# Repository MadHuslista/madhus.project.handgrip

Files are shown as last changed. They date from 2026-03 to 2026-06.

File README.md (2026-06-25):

# Handgrip Suite

- [Handgrip Suite](#handgrip-suite)
  - [Summary](#summary)
    - [System Architecture](#system-architecture)
    - [Components](#components)
  - [Quickstart](#quickstart)
    - [Firmware Workspace](#firmware-workspace)
    - [Python Workspace](#python-workspace)
    - [What to read and when](#what-to-read-and-when)
  - [Validation](#validation)
  - [Documentation map](#documentation-map)

## Summary

- **Handgrip Suite** is an end-to-end suite for acquiring, visualizing, calibrating, and analyzing handgrip force data.
- The system combines a **target handgrip device** based on Arduino Nano + HX711 load-cell acquisition with a **reference force chain** based on a PM58 load cell connected to a high-speed RS485 acquisition board.
- The host software stack is split into 5 focused components: `RS485_GUI`, `LSL_Bridge`, `LSL_Viewer`, `Handgrip_Calibration`, and `Handgrip_Analysis`.
- The documentation is organized for progressive discovery: each README provides a self-contained overview of its component, with links to more detailed workflows and references.
- This root README is intentionally short. The full documentation map starts at [docs/index.md](docs/index.md).

### System Architecture

```mermaid
flowchart TD
    Streams>"Dual Streams"]
    Hardware("PM58 Load Cell \n& Acquisition Board\n(reference)") -->|Modbus RS485| RS485_GUI(RS485 GUI)
    RS485_GUI -->|ZeroMQ IPC| Bridge(LSL_Bridge)
    FW("Handgrip_Firmware \nADC: HX711 &\nMCU: Arduino Nano\n(target)\n") -->|UART Serial| Bridge
    Bridge --> |s: HandgripReference| Streams
    Bridge ~~~ |"LSL Streams\n Sync capables"| Streams
    Bridge --> |s: HandgripTarget| Streams
    Streams -->| Live | Viewer(LSL_Viewer)
    Streams -->|Captured Data| Calibration(Handgrip_Calibration)
    Calibration -->|Calibration Data/Files| Analysis(Handgrip_Analysis)
```

### Components

Following the system architecture, here are the entry points and purposes for each module:

- [PM58 Load Cell & Acquisition Board](docs/workflows/physical-setup.md): Reference-force sensing hardware and wiring stack. 
- [RS485_GUI](RS485_GUI/docs/index.md): Control interface for reading PM58 data and streaming it to LSL_Bridge in real time. 
- [Handgrip_Firmware](Handgrip_Firmware/docs/index.md): Firmware that samples HX711 load-cell data and sends UART telemetry. 
- [LSL_Bridge](LSL_Bridge/docs/index.md): Middleware that ingests target/reference signals and publishes synchronized LSL streams.
- [LSL_Viewer](LSL_Viewer/docs/index.md): Real-time dashboard for monitoring synchronized LSL streams.
- [Handgrip_Calibration](Handgrip_Calibration/docs/index.md): Identifies the best mathematical model to map raw ADC counts to Newtons using reference-force ground truth. 
- [Handgrip_Analysis](Handgrip_Analysis/docs/index.md): DSP analysis workflow for selecting production filter parameters for LSL_Bridge.

## Quickstart

### Firmware Workspace

Install PlatformIO from: 

| Option | Link |
| --- | --- |
| CLI Standalone | [https://docs.platformio.org/en/latest/core/installation/index.html](https://docs.platformio.org/en/latest/core/installation/index.html) |
| VSCode extension [**Recommended**] | [https://marketplace.visualstudio.com/items?itemName=platformio.platformio-ide](https://marketplace.visualstudio.com/items?itemName=platformio.platformio-ide) |

Ensure PlatformIO binaries are in your PATH: 
- [https://docs.platformio.org/en/stable/core/installation/shell-commands.html](https://docs.platformio.org/en/stable/core/installation/shell-commands.html)

Firmware is built with PlatformIO from the root `platformio.ini`
Run from the repository root:

```bash
pio run -e nanoatmega328
pio run -e nanoatmega328 -t upload
```

Validate connection and data reception with:

```bash
pio device monitor -e nanoatmega328
```
Expect to see a stream of telemetry lines with raw ADC counts and timestamps. 

Read [Handgrip_Firmware/docs/workflow.md](Handgrip_Firmware/docs/workflow.md) for the full workflow, or before uploading or changing firmware constants.

### Python Workspace

Install UV Python package manager from: 
- [https://docs.astral.sh/uv/getting-started/installation/](https://docs.astral.sh/uv/getting-started/installation/)

Run from the repository root:

```bash
uv venv .venv
source .venv/bin/activate
uv sync
```

From repository root, run the live system in this order:

```bash
# Terminal 1 — reference acquisition board GUI / IPC publisher
uv run rs485-gui serial.default_port=/dev/ttyUSB_RS485

# Terminal 2 — target/reference bridge to Lab Streaming Layer
uv run lsl-bridge serial.port=/dev/ttyUSB_TARGET

# Terminal 3 — live viewer
uv run lsl-viewer
```

This brings up the reference GUI/IPC publisher, the `HandgripTarget` and `HandgripReference` LSL streams, and the viewer UI. For the full operational path, read [docs/workflows/full-live-viewer-quickstart.md](docs/workflows/full-live-viewer-quickstart.md).

### What to read and when

| I want to… | Start here | Then |
| --- | --- | --- |
| Understand the whole suite | [docs/system-overview.md](docs/system-overview.md) | [docs/workflows/handgrip-calibration.md](docs/workflows/handgrip-calibration.md), [docs/workflows/handgrip-analysis.md](docs/workflows/handgrip-analysis.md) |
| Connect hardware | [docs/workflows/physical-setup.md](docs/workflows/physical-setup.md) | [Handgrip_Firmware/docs/workflow.md](Handgrip_Firmware/docs/workflow.md) |
| Start the full live system | [docs/workflows/full-live-viewer-quickstart.md](docs/workflows/full-live-viewer-quickstart.md) | — |
| Validate target path only | [docs/workflows/target-only-quickstart.md](docs/workflows/target-only-quickstart.md) | — |
| Validate reference path only | [docs/workflows/reference-only-quickstart.md](docs/workflows/reference-only-quickstart.md) | — |
| Build/upload firmware | [Handgrip_Firmware/docs/workflow.md](Handgrip_Firmware/docs/workflow.md) | [Handgrip_Firmware/docs/index.md](Handgrip_Firmware/docs/index.md) |
| Calibrate the handgrip | [docs/workflows/handgrip-calibration.md](docs/workflows/handgrip-calibration.md) | [Handgrip_Calibration/docs/workflow.md](Handgrip_Calibration/docs/workflow.md) |
| Run signal analysis | [docs/workflows/handgrip-analysis.md](docs/workflows/handgrip-analysis.md) | [Handgrip_Analysis/docs/workflow.md](Handgrip_Analysis/docs/workflow.md) |
| Understand repo structure | [docs/architecture/repository-layout.md](docs/architecture/repository-layout.md) | — |
| Troubleshoot | [docs/troubleshooting/index.md](docs/troubleshooting/index.md) | Component `*/docs/` links |

## Validation

After the [Quickstart](#quickstart) install, validate the workspace from the repository root:

```bash
uv run pytest
```

The root `pyproject.toml` installs the local Python components as editable packages:

- `rs485-gui`
- `lsl-bridge`
- `lsl-viewer`
- `handgrip-calibration`
- `handgrip-analysis`

## Documentation map

The full documentation map — section tree and component entry points — starts at [docs/index.md](docs/index.md).

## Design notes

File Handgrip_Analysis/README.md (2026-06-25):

# Handgrip Analysis

## Summary

`Handgrip_Analysis` is the offline signal-analysis and filter-design package for captured handgrip data. It runs staged analyses to characterize startup drift, stationary noise, loaded drift/creep, real handgrip dynamics, interference conditions, and candidate digital filters.

It is file-based by design. Use it after acquisition/calibration data exists, not as the live acquisition authority.

## First command

New recordings can be done with the `LSL_Bridge`. 
After recording, copy the generated CSV files to `Handgrip_Analysis/data/calibration_signals/` and update the corresponding manifest in `Handgrip_Analysis/data/manifests/` before running the analysis.

All `uv run ha-...` commands below can be run from the repo root or from
`Handgrip_Analysis/` — `data/...` and `conf/...` paths resolve to
`Handgrip_Analysis/data/...` and `Handgrip_Analysis/conf/...` either way:

```bash
uv run ha-run-all --help
```

Run a single stage with the relevant stage entry point. Example static-noise run:

```bash
uv run ha-stage2 manifest=data/manifests/stage2_manifest.csv outdir=data/analysis_results/stage2
```

Run from a manifest when prepared:

```bash
uv run ha-run-all \
  manifest=path/to/capture_manifest.csv \
  base_outdir=outputs/batch_run
```

## Quickstart 
  
Initial Handgrip recordings done following [Handgrip_Analysis/docs/stages.md](docs/stages.md) are available in `data/calibration_signals/` and indexed in `data/manifests/`.

To observe the analysis results on these example recordings, run (from the repo root or `Handgrip_Analysis/`):

```bash
# Per-stage analysis:
ha-run-all manifest=data/manifests/analysis_stages_1_4_manifest.csv base_outdir=data/analysis_results stages=stage1,stage2,stage3,stage4
```

```bash
# Filter design review:
ha-stage stage=stage6 manifest=data/manifests/stage6_filter_review_manifest.csv outdir=data/analysis_results/stage6 filter_config=conf/filters/candidates.yaml
```

On new recordings, make sure to clean the output directory to ensure that the analysis runs with a clean slate and that all expected outputs are generated.

## Expected results

**Stage 1-5**: Metrics and plots characterizing startup drift, stationary noise, loaded drift/creep, real handgrip dynamics, and interference conditions.

**Stage 6**: 
Candidate filter performance metrics, plots, and a filter recommendation based on the selected policy.
In particular review: 
- Filter Design Report  : `data/analysis_results/stage6/stage6_review_design_report.md`
- Acceptance Report     : `data/analysis_results/stage6/filter_acceptance_report.md`

## Configuration

Primary config tree:

```text
Handgrip_Analysis/conf/
├── config.yaml
├── analysis/
│   ├── stage1.yaml
│   ├── stage2.yaml
│   ├── stage3.yaml
│   ├── stage4.yaml
│   ├── stage5.yaml
│   └── stage6.yaml
├── dsp/
├── filters/
└── io/
```

Main configuration areas:

| Area | Purpose |
| --- | --- |
| input / manifest  | Source CSVs, labels, channel mapping, batch dispatch. |
| output / IO | Output directory, overwrite policy, report paths. |
| stage configs | Stage-specific windows, metrics, plots, thresholds. |
| DSP defaults | Sampling assumptions, filtering utilities, spectral settings. |
| filter candidates | Candidate families and parameters for Stage 6 evaluation. |

Full configuration reference: [Handgrip_Analysis/docs/configuration.md](docs/configuration.md).

## Documentation

Full reading guide, per-document map, and related cross-component docs: [Handgrip_Analysis/docs/index.md](docs/index.md).

## Repository layout

```text
Handgrip_Analysis/
├── README.md
├── conf/
│   ├── config.yaml
│   ├── analysis/
│   ├── dsp/
│   ├── filters/
│   └── io/
├── docs/
│   └── index.md
├── scripts/
│   ├── stage1_startup_warmup.py
│   ├── stage2_static_noise.py
│   ├── stage3_loaded_drift.py
│   ├── stage4_grip_dynamics.py
│   ├── stage5_interference_compare.py
│   ├── stage6_filter_design.py
│   └── run_all.py
├── src/
│   └── handgrip_analysis/
└── tests/
```

## Tests

Run from `Handgrip_Analysis/` after dependencies are installed (`uv run pytest`
discovers `tests/` relative to cwd, so this must run from `Handgrip_Analysis/`):

```bash
uv run pytest
```

For a quick CLI smoke check (can run from the repo root or `Handgrip_Analysis/`):

```bash
uv run ha-run-all --help
uv run ha-stage1 --help
uv run ha-stage6-design --help
```

If your installed entry points differ, check the active `pyproject.toml` and update this README plus [docs/workflows/handgrip-analysis.md](../docs/workflows/handgrip-analysis.md) together.

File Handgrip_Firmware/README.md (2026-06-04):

# Handgrip Firmware

## Summary

`Handgrip_Firmware` runs on the Arduino Nano target device. It reads the handgrip load-cell path through the HX711, emits schema-2 serial frames over USB UART, and provides the raw target signal consumed by `LSL_Bridge`.

Current firmware contract:

```text
M2,<payload_schema>,<firmware_version>,<git_sha>,<expected_rate_hz>,<scale_factor>,<scale_offset>,<unit>
D2,<seq>,<timestamp_us>,<raw_count>,<current_units>,<status>
```

`raw_count` is the calibration-authoritative target value. `current_units` is a firmware-scaled convenience value and should not replace raw-count fitting unless a workflow explicitly says so.

## First command

From the repository root:

```bash
platformio run -e nanoatmega328
```

Upload after a successful build:

```bash
platformio run -e nanoatmega328 -t upload
```

Open the serial monitor:

```bash
platformio device monitor --baud 115200
```

## Expected result

After upload and reset, the serial monitor should show one metadata line followed by D2 sample lines:

```text
M2,2,...
D2,<seq>,<timestamp_us>,<raw_count>,<current_units>,<status>
```

Expected validation points:

- `seq` increases monotonically,
- `timestamp_us` increases over time,
- `raw_count` changes when force changes,
- `status` is usually `0` or only occasionally nonzero,
- downstream `LSL_Bridge` can publish `HandgripTarget`.

Stop if the serial monitor shows the deprecated legacy D-prefix frame instead of `D2`.

## Configuration

Primary configuration files:

| File | Purpose |
| --- | --- |
| `Core/Inc/config.h` | Firmware constants: serial baud, payload schema, sampling period, scale factor, offset, status bits. |
| `Core/Src/main.cpp` | HX711 setup, TimerOne acquisition, FIFO handoff, M2/D2 emission. |
| `../platformio.ini` | PlatformIO environment, board, dependencies, upload/monitor settings. |

Important constants:

| Constant / concept | Meaning |
| --- | --- |
| `SCALE_FACTOR` | Firmware-side scale used for `current_units`.  |
| `SCALE_OFFSET` | Firmware-side offset used for `current_units`. |
| `SAMPLING_PERIOD_US` | Timer tick for non-blocking HX711 polling. |
| `HANDGRIP_PAYLOAD_SCHEMA` | Current payload schema. Expected value: `2`. |
| `HANDGRIP_FORCE_UNIT` | Unit emitted in M2 metadata, normally `N`. |

Full configuration reference: [Handgrip_Firmware/docs/configuration.md](docs/configuration.md).

## Documentation

Full reading guide, per-document map, and related cross-component docs: [Handgrip_Firmware/docs/index.md](docs/index.md).

## Repository layout

```text
Handgrip_Firmware/
├── README.md
├── docs/
│   ├── index.md
│   └── serial-protocol.md
└── Core/
    ├── Inc/
    │   ├── config.h
    │   └── fifo_buffer.h
    └── Src/
        └── main.cpp
```

## Tests

There is no standalone firmware unit-test suite in this component. Validate firmware behavior through build/upload and serial output checks:

```bash
platformio run -e nanoatmega328
platformio run -e nanoatmega328 -t upload
platformio device monitor --baud 115200
```

Then verify D2 stream consumption through `LSL_Bridge` and the target-only quickstart.

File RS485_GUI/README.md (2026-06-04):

# RS485 GUI

## Summary

`RS485_GUI` is the reference-chain acquisition application. It connects to the high-speed acquisition board over RS485, displays reference measurements in a browser UI, logs acquisition data, and publishes normalized reference measurements over ZeroMQ IPC for `LSL_Bridge`.

It owns the PM58/acquisition-board host-side acquisition path. Downstream components should consume its IPC output through `LSL_Bridge`, not reimplement board parsing independently.

## First command

From `RS485_GUI/`:
> This should be enough to start the application with default settings ready to connect to the acquisition board if it's on a standard port. 
> Adjustments could be done directly on the UI or by providing config overrides as needed.

```bash
uv run rs485-gui
```

With an explicit serial port:

```bash
uv run rs485-gui serial.default_port=/dev/ttyUSB_RS485
```

With a custom UI port:

```bash
uv run rs485-gui ui.port=8090 serial.default_port=/dev/ttyUSB_RS485
```

## Expected result

Expected successful behavior:

- the NiceGUI browser interface opens,
- the acquisition board value updates when force changes,
- logs show valid board measurements,
- the IPC publisher is active on the configured endpoint/topic,
- `LSL_Bridge` can consume the `rs485.measurement.v1` IPC stream and publish `HandgripReference`.

Stop if the acquisition-board front display changes but the GUI receives no valid measurements.

## Configuration

Primary config:

```text
RS485_GUI/config/config.yaml
```

Main configuration areas:

| Area | Purpose |
| --- | --- |
| `serial` / transport settings | Port, baud, mode, Modbus/Active-Send profile. |
| `ui` | Browser UI host/port, refresh cadence, plot behavior. |
| `logger` | CSV/NDJSON/event logging behavior and output paths. |
| `ipc` | ZeroMQ publisher endpoint and topic configuration. |
| `parser` / signal settings | Board payload interpretation and selected displayed signal. |

Full configuration reference: [RS485_GUI/docs/configuration.md](docs/configuration.md).

## Library layout

```text
RS485_GUI/
├── README.md
├── config/
│   └── config.yaml
├── docs/
│   └── index.md
├── src/
│   └── rs485_gui/
│       ├── app.py
│       ├── worker.py
│       ├── core/
│       ├── transport/
│       ├── io/
│       ├── ui/
│       └── config/
└── tests/
```

## Tests

Run from `RS485_GUI/` after dependencies are installed:

```bash
uv run pytest
```

Use targeted tests when changing one layer:

```bash
uv run pytest tests/unit
uv run pytest tests/integration
```

If hardware is unavailable, prioritize parser/config/unit tests and validate live acquisition later with the reference-only quickstart.

## Documentation

Full reading guide, per-document map, and related cross-component docs: [RS485_GUI/docs/index.md](docs/index.md).

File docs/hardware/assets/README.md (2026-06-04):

# Hardware Image Asset Map

## Summary

This directory is the canonical image location for hardware documentation. Hardware Markdown files under `docs/hardware/` should reference images through relative paths such as `assets/acquisition-board-rear-terminal-map-full-feature.jpg`.

Images are named by **hardware role + visible content**, not by capture timestamp. Filenames use lowercase kebab-case so links are stable and readable in GitHub.

## Operator image set

| File | Shows | Primary use |
| --- | --- | --- |
| `acquisition-board-rear-terminal-map-full-feature.jpg` | Rear terminal map for the full-feature acquisition board. | Terminal identification for power, RS485, analog output, DI, and PM58 sensor wiring. |
| `acquisition-board-ac-input-label-100-240vac.jpg` | AC input label showing `AC100-240V`, `L`, and `N`. | Confirms the exact board variant before applying mains power. |
| `acquisition-board-front-panel-buttons-indicators.jpg` | Front display, four keys, status LEDs, and indicators. | Menu navigation, zero/calibration actions, display validation. |
| `acquisition-board-front-panel-startup-force-reading.jpg` | Front panel powered with a live reading during bench use. | First power-on / live-response visual reference. |
| `acquisition-board-rear-label-google-lens-translation.jpg` | Phone-captured translated rear label. | Human-readable cross-check when the printed rear label is hard to interpret. |
| `pm58-load-cell-model-label.jpg` | PM58 load-cell model and range label. | Confirms model identity and nominal 100 kg range. |
| `pm58-load-cell-certificate-overview.jpg` | PM58 product certificate overview. | Certificate-level identification and range/sensitivity context. |
| `pm58-load-cell-certificate-wire-colors.jpg` | PM58 certificate with visible wire-color mapping. | Confirms `EXC+ red`, `EXC- black`, `SIG+ green`, `SIG- white`, shield/drain. |
| `force-fixture-pm58-handgrip-series-overhead.jpg` | PM58 and handgrip target mechanically arranged in series. | Fixture stage 1: shared mechanical force path. |
| `force-fixture-pm58-handgrip-acquisition-board-overview.jpg` | PM58 + handgrip fixture with acquisition board present. | Fixture stage 2: mechanical path plus reference electronics. |
| `force-fixture-screw-press-pm58-handgrip-closeup.jpg` | Screw press applying controlled force through PM58 + handgrip. | Fixture stage 3: controlled-force contact and alignment. |
| `force-fixture-full-bench-screw-press-acquisition-board.jpg` | Full bench view with screw press, PM58, handgrip, and acquisition board. | Overall calibration bench layout and cable routing. |
| `handgrip-internal-load-cell-distal-side.jpg` | Internal handgrip load cell and wire routing on the distal side. | Target-device mechanical/electrical inspection. |
| `handgrip-internal-load-cell-proximal-side.jpg` | Internal handgrip load cell and wire routing on the proximal side. | Target-device mechanical/electrical inspection. |
| `hx711-sensor-to-adc-module-wiring.jpg` | Sensor wiring landing on the HX711 ADC module. | Target analog front-end wiring reference. |
| `hx711-adc-module-to-arduino-wiring.jpg` | HX711 ADC module wiring routed toward Arduino Nano. | Target ADC-to-MCU wiring reference. |
| `hx711-adc-chip-closeup.jpg` | HX711 chip / ADC module part-number close-up. | ADC module identification. |
| `arduino-nano-pinout-closeup.jpg` | Arduino Nano close-up showing board and pin labels. | MCU board identification and pinout reference. |
| `arduino-nano-mounted-wiring-view.jpg` | Arduino Nano mounted inside the handgrip wiring cavity. | Target firmware hardware context and installed wiring reference. |

## Duplicate / retained reference asset

| File | Shows | Note |
| --- | --- | --- |
| [`force-fixture-pm58-handgrip-series-overhead-duplicate.jpg`](force-fixture-pm58-handgrip-series-overhead-duplicate.jpg) | Same PM58 + handgrip series view as [`force-fixture-pm58-handgrip-series-overhead.jpg`](force-fixture-pm58-handgrip-series-overhead.jpg). | Exact duplicate retained only so the original asset count is preserved; operator docs use the canonical non-duplicate filename. |

## Rendering guidance

- In operator-facing Markdown, prefer compact image tables with clear captions instead of repeating the same large photo in every step.
- Use images near the top of the workflow as a visual reference set, then refer to them by figure number in the step-by-step sections.
- For GitHub rendering, use relative paths (`assets/<file>.jpg`) and avoid absolute repository URLs.
- For plain Markdown rendering, keep the caption text outside the image `alt` field so the caption remains visible even when image sizing HTML is ignored.

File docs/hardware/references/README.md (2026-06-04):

# Hardware Reference PDFs

## Summary

This directory stores source PDFs used by the hardware documentation. Operator workflows should link here instead of relying only on external URLs.

## Reference map

| File | Purpose | Used by |
| --- | --- | --- |
| [`acquisition-board/acquisition-board-instruction-manual-original-v3.pdf`](acquisition-board/acquisition-board-instruction-manual-original-v3.pdf) | Original acquisition-board instruction manual, bilingual/Chinese-source version. | Acquisition-board reference and PM58 wiring cross-checks. |
| [`acquisition-board/acquisition-board-instruction-manual-machine-translated-en-v3.pdf`](acquisition-board/acquisition-board-instruction-manual-machine-translated-en-v3.pdf) | Machine-translated English acquisition-board manual. | Menu and wiring interpretation fallback. |
| [`acquisition-board/acquisition-board-provider-offer-screencapture-2026-04-08.pdf`](acquisition-board/acquisition-board-provider-offer-screencapture-2026-04-08.pdf) | Provider offer / product-page capture for acquisition-board identity context. | Hardware provenance and variant confirmation. |
| [`hx711/hx711-datasheet-english.pdf`](hx711/hx711-datasheet-english.pdf) | HX711 English datasheet. | Target ADC rate, settling, and bridge-ADC behavior reference. |

## Usage rule

Use these PDFs as supporting references. The executable setup instructions remain in the Markdown workflows under `docs/hardware/`.

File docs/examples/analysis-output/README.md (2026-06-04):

# Curated Analysis Output Example

## Summary

Small, curated excerpts showing how to read analysis outputs, especially Stage 6 filter-design artifacts.

## Stage 6 example interpretation

The current curated conclusion from prior Stage 6 work is:

- Keep the raw channel for traceability.
- Do not use continuous high-pass filtering as the primary force path.
- Do not use band-pass filtering as the primary force path.
- Notch filtering is not needed for the main product path if a modest low-pass already removes high-frequency contamination.
- Primary filtered channel recommendation: **2nd-order Butterworth low-pass at 9 Hz, fs = 100 Hz** (`butter_lowpass_9hz`).
- Optional secondary stable-display channel: **2nd-order Butterworth low-pass at 10 Hz, fs = 100 Hz**.
- Baseline/zero handling should be state-based tare/unloaded baseline tracking, not continuous high-pass filtering during grip events.

## Important Stage 6 artifacts

| Artifact | Purpose | How to use |
| --- | --- | --- |
| `stage6_review_design_report.md` | Human-readable review/design report. | Start here for reasoning and final recommendation. |
| `filter_acceptance_report.md` | Acceptance/failure analysis for candidates. | Check why candidates passed/failed constraints. |
| `filter_ranking_summary.csv` | Candidate ranking. | Inspect top candidates and composite scores. |
| `filter_validation_scores.csv` | Validation scores. | Check whether a filter generalizes across trials/sessions. |
| `filter_decision_summary.csv` | Compact decision table. | Use in handoff reports. |
| `filter_design_assessment.csv` | Per-candidate design assessment. | Audit filter tradeoffs. |
| `lsl_bridge_processing_recommendation.yaml` | Candidate deployment config for `LSL_Bridge`. | Copy only after validation and review. |
| `selected_filter_recommendation.json` | Machine-readable selected recommendation. | Preserve for reproducibility. |
| `figures/aggregate/stage6_design_representative_overlay.png` | Visual overlay of representative input/filter output. | Check waveform realism. |

## What not to do

- Do not deploy the smoothest-looking filter automatically.
- Do not remove the raw channel.
- Do not treat Stage 6 output as calibration proof; it is a signal-processing recommendation.
- Do not apply high-pass or band-pass filters to the primary force path unless a new validated analysis overturns the current evidence.

## Deployment review checklist

Before copying `lsl_bridge_processing_recommendation.yaml` into the live bridge config:

- [ ] Candidate filter is selected by Stage 6 evidence, not just appearance.
- [ ] Peak preservation and peak-time shift are acceptable.
- [ ] Rise-time / derivative behavior remains realistic.
- [ ] Hold stability improves or remains acceptable.
- [ ] Calibration residuals do not degrade after deployment.
- [ ] Raw data remains logged or streamable.

## Curation rule

This directory may contain short narrative excerpts and selected tables. Keep full generated output in `Handgrip_Analysis/data/analysis_results/`.

## Related docs:

- [docs/workflows/handgrip-analysis.md](../../workflows/handgrip-analysis.md)
- [Handgrip_Analysis/docs/filter-design.md](../../../Handgrip_Analysis/docs/filter-design.md)
- [Handgrip_Analysis/docs/reports-and-outputs.md](../../../Handgrip_Analysis/docs/reports-and-outputs.md)

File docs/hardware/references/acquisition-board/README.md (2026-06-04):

# Acquisition Board Reference PDFs

| File | Contents |
| --- | --- |
| [`acquisition-board-instruction-manual-original-v3.pdf`](acquisition-board-instruction-manual-original-v3.pdf) | Original acquisition-board instruction manual. |
| [`acquisition-board-instruction-manual-machine-translated-en-v3.pdf`](acquisition-board-instruction-manual-machine-translated-en-v3.pdf) | Machine-translated English acquisition-board instruction manual. |
| [`acquisition-board-provider-offer-screencapture-2026-04-08.pdf`](acquisition-board-provider-offer-screencapture-2026-04-08.pdf) | Provider/product-page capture. |

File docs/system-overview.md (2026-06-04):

# System Overview — Handgrip Suite

## What the suite does

The Handgrip Suite measures handgrip force by comparing a target handgrip sensor against a PM58 reference load cell. It answers two questions:

- **Calibration:** how do I map target raw ADC counts to reference force in Newtons?
- **Analysis:** what are the signal quality, drift, noise, and dynamics, and which filter parameters should be used in production?

The suite has two physical measurement paths:

- **Target path:** Arduino Nano + HX711 load-cell ADC, emitting serial data to `LSL_Bridge`.
- **Reference path:** PM58 load cell → acquisition board → RS485 → `RS485_GUI` → ZeroMQ IPC → `LSL_Bridge`.

The normal live workflow starts the reference acquisition app first, then the LSL bridge, then the viewer.

## Physical chain

The target path runs: Handgrip sensor → HX711 ADC → Arduino Nano firmware → USB serial → `LSL_Bridge` → `HandgripTarget` LSL stream. The reference path runs: PM58 load cell → acquisition board → RS485 → `RS485_GUI` → ZeroMQ IPC → `LSL_Bridge` → `HandgripReference` LSL stream. For the full dataflow diagram see [docs/architecture/dataflow.md](architecture/dataflow.md).

During calibration the target and reference chains must experience the same mechanical force path. See [docs/hardware/force-fixture.md](hardware/force-fixture.md).

## Software processes

| Process / command | Component | Main input | Main output | Start order |
| --- | --- | --- | --- | --- |
| `uv run rs485-gui` | `RS485_GUI` | Acquisition board through RS485 | GUI plots, logs, ZeroMQ IPC | 1 |
| `uv run lsl-bridge` | `LSL_Bridge` | Arduino serial + RS485 GUI IPC  | LSL streams, optional CSV logs | 2 |
| `uv run lsl-viewer` | `LSL_Viewer` | LSL streams or replay files | Browser visualization | 3 |
| `uv run handgrip-cal ...` | `Handgrip_Calibration` | LSL streams / recorded sessions | Calibration datasets, reports | 4 |
| `uv run ha-stage ...` / `uv run ha-run-all ...` | `Handgrip_Analysis` | CSV inputs and manifests | Analysis reports, filter recommendations | Offline |

For end-to-end dataflow see [docs/architecture/dataflow.md](architecture/dataflow.md).

## Stream and data contracts

Contracts in this suite: firmware UART (`M2`/`D2`), RS485 IPC (`rs485.measurement.v1`), and three LSL streams (`HandgripTarget`, `HandgripReference`, `HandgripComponentEvents`). Full ownership map and authoritative definitions: [docs/architecture/stream-contracts.md](architecture/stream-contracts.md).

## Output locations

| Component | Common output location | Output type |
| --- | --- | --- |
| `RS485_GUI` | `RS485_GUI/logs/` or configured paths | Logs, CSV, NDJSON |
| `LSL_Bridge` | `LSL_Bridge/logs/`, configured CSV paths | Target/reference CSVs, bridge logs |
| `LSL_Viewer` | Display-only; replay paths in `conf/config.yaml` | Browser UI |
| `Handgrip_Calibration` | `Handgrip_Calibration/data/calibration/<session_id>/` | CSVs, events, fit outputs, reports |
| `Handgrip_Analysis` | `Handgrip_Analysis/data/analysis_results/` | Stage reports, figures, filter recommendations |

Generated outputs are not canonical documentation unless curated under [docs/examples](examples/).

Full configuration map: [docs/configuration/index.md](configuration/index.md).

## Typical first-time sequence

1. Connect hardware and wire PM58. See [docs/workflows/physical-setup.md](workflows/physical-setup.md).
2. Upload firmware and validate serial output. See [Handgrip_Firmware/docs/workflow.md](../Handgrip_Firmware/docs/workflow.md).
3. Validate the reference chain. See [docs/workflows/reference-only-quickstart.md](workflows/reference-only-quickstart.md).
4. Validate the target chain. See [docs/workflows/target-only-quickstart.md](workflows/target-only-quickstart.md).
5. Start the full live viewer. See [docs/workflows/full-live-viewer-quickstart.md](workflows/full-live-viewer-quickstart.md).
6. Calibrate the handgrip. See [docs/workflows/handgrip-calibration.md](workflows/handgrip-calibration.md).
7. Run signal analysis. See [docs/workflows/handgrip-analysis.md](workflows/handgrip-analysis.md).

## Where to go next

| If you want to… | Start here |
| --- | --- |
| Connect hardware and wire PM58 | [docs/workflows/physical-setup.md](workflows/physical-setup.md) |
| Upload firmware and validate serial | [Handgrip_Firmware/docs/workflow.md](../Handgrip_Firmware/docs/workflow.md) |
| Start the full live system | [docs/workflows/full-live-viewer-quickstart.md](workflows/full-live-viewer-quickstart.md) |
| Calibrate the handgrip | [docs/workflows/handgrip-calibration.md](workflows/handgrip-calibration.md) |
| Run signal analysis | [docs/workflows/handgrip-analysis.md](workflows/handgrip-analysis.md) |
| Understand a specific component | Component `*/docs/index.md` files |
| Modify or extend the code | Component `*/docs/development.md` files |
| Troubleshoot a problem | [docs/troubleshooting/index.md](troubleshooting/index.md) |

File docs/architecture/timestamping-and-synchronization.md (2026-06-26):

# Timestamping and Synchronization

## Summary

- Timing is a system property, not a single-module detail.
- The target stream is device-paced and should be treated as irregular due limitations of the HX711 ADC.
- The reference stream is expected to be faster and more regular, typically using the acquisition board Active-Send profile.
- LSL timestamps should preserve enough information to support post-hoc alignment, interpolation, and lag diagnostics.
- Viewer downsampling is display-only and must not be confused with acquisition downsampling.

## Timing model

```markdown
Target path timing
  HX711 conversion → firmware timestamp_us → USB serial receive → LSL_Bridge timestamp → 
  emits LSL sample @ `irregular` 93 ~ 100 Hz

Reference path timing
  acquisition-board ADC/sample → RS485 frame → RS485_GUI receive → IPC publish → LSL_Bridge receive → 
  emits LSL sample @ `regular` 500 Hz (Active-Send)
```

## Target stream timing

The target firmware includes `timestamp_us` in D2 frames. This is valuable because it helps separate:

- physical sampling time,
- serial transport delay,
- host receive time,
- LSL publication time.

Recommended treatment:

- Advertise target as irregular unless a future firmware version proves stable fixed-rate behavior.
- Preserve `seq` for drop detection.
- Preserve `timestamp_us` for gap and drift diagnostics.

## Reference stream timing

The acquisition board is configured in `Active-Send` mode, which sets the board to emit frames at a fixed rate.
This is valuable because it makes the effective sampling rate, regular and independent of the inherent jitter of the Host's OS scheduler reading rate.

However, the frames carry **no acquisition timestamp** —force/status only—, so the reference sample timestamp must be reconstructed from the host read time (`rs485_clock = host_lsl_ts`) of the last batch of buffered frames, and the known frame interval `rs485_frame_dt_s` (the reciprocal of the Active-Send rate). 

This means the reference is only effectively timestamped thanks to the GUI reconstruction.

The recommended calibration profile uses high-rate acquisition and Active-Send after parser stability by the board control interface (`RS485_GUI`) has been validated.

Recommended treatment:

- Use a high enough serial baud rate for the chosen reference output rate.
- Keep hidden board features such as auto-zero, dynamic tracking, and display-only zero masking disabled during calibration captures.
- Treat Modbus RTU polling as a documented fallback if Active-Send parsing or timing is not stable (not recommended).

## Reference relay offset and host-read-time stamping

The reference is effectively timestamped when the GUI *reads* the latest batch of buffered frames, i.e. after the relay hop `board → RS485 → RS485_GUI → IPC → LSL_Bridge`. 
The target, by contrast, reaches the bridge directly over USB. 

For the *same physical instant*, the two streams receive LSL timestamps that differ by the difference in those read latencies — a stable **relay offset** (order ~100 ms), not a rendering bug.

If present, this relay offset will be observed in the LSL Viewer XY plot (reference vs. target), as a **staircasing** waveform. 

To trigger it, set the `LSL_Viewer` parameter `manual_reference_shift_s = 0`, reload the viewer, and apply the same sudden change on force to both devices simultaneously (i.e. with both devices set as done on the calibration setup).

Under this condition, the signals should rise together drawing a 1:1 diagonal line, but the reference will arrive late, so the plot will first jump vertically (target changes, reference not yet updated), and then horizontally (reference updates to match target).

To compensate for this, an utility script `calibration_preflight.py` is [provided](../../Handgrip_Calibration/scripts/calibration_preflight.py) to measure the relay offset and confirm the absence of other timing issues (see [Handgrip_Calibration/docs/recording.md](../../Handgrip_Calibration/docs/recording.md) for instructions).

The result is a single scalar value that quantifies the relay offset, which needs to be set in the viewer as `manual_reference_shift_s` to align the reference timestamps with the target timestamps.

> Note that this is a compensation for the relay offset, not a correction of the acquisition timestamps, so it is **topology/host dependent**: re-measure it whenever the physical or runtime setup changes.

## LSL timing responsibilities

`LSL_Bridge` is responsible for publishing target/reference samples to LSL. It should also expose enough operational information for debugging timing problems.

| Responsibility | Why it matters |
| --- | --- |
| Preserve target sequence numbers | Detect dropped target samples. |
| Preserve or derive timestamps consistently | Align target and reference streams. |
| Emit component events | Diagnose connects, disconnects, parser failures, gaps. |
| Avoid display-only transformations in data streams | Calibration must use raw/reference data, not viewer convenience transforms. |

## Practical validation tests

### Target timing test

- Run firmware serial monitor.
- Collect at least 10 seconds of D2 frames.
- Check `seq` monotonicity.
- Check `timestamp_us` increments and gap distribution.

### Reference timing test

- Run `RS485_GUI` in the intended mode.
- Confirm frame rate near target profile.
- Check logs for parser recovery or malformed frames.

### LSL timing test

- Run bridge and viewer.
- Confirm target/reference streams update simultaneously under a visible force change.
- Record a short calibration/preflight session and inspect saved sample counts.

## Related docs:
- [docs/architecture/stream-contracts.md](stream-contracts.md)
- [docs/workflows/handgrip-calibration.md](../workflows/handgrip-calibration.md)

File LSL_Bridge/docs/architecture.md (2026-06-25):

# LSL Bridge Architecture

## Summary

- `LSL_Bridge` is a Hydra-driven runtime application that connects target firmware serial input and RS485 GUI IPC input to LSL outlets.
- The target loop runs in the foreground and auto-reconnects on serial exceptions.
- The reference IPC publisher runs in a background daemon thread.
- Component events are published as a sparse LSL marker stream.
- Optional CSV sinks persist the exact target/reference samples published by the bridge.

## Runtime lifecycle

```text
main()
  → Hydra config load
  → configure logging
  → build HandgripComponentEvents outlet
  → open target/reference CSV sinks
  → build HandgripReference outlet
  → start RS485 IPC reference publisher thread
  → build parser, processor, timestamp resolvers
  → serial reconnect loop
      → open target serial port
      → settle serial input
      → build HandgripTarget outlet
      → read D2 lines
      → parse target sample
      → resolve LSL timestamp
      → process target_current_units
      → push HandgripTarget sample
      → write target CSV
  → KeyboardInterrupt
      → emit bridge_stop
      → stop reference publisher
      → close CSV sinks
```

## Source module map

| Module | Responsibility |
| --- | --- |
| `lsl_bridge.app` | Main Hydra entry point and lifecycle orchestration. |
| `lsl_bridge.core.parser` | Strict D2/M2 target UART parser and metadata handling. |
| `lsl_bridge.core.timestamping` | Target LSL timestamp policy and processor-domain time resolution. |
| `lsl_bridge.core.filter` | Current target processing implementation. |
| `lsl_bridge.core.processing` | Runtime processor module loading / processor factory. |
| `lsl_bridge.io.lsl_outlets` | Build target/reference LSL StreamInfo and outlets. |
| `lsl_bridge.io.csv_sinks` | Persist target/reference samples to CSV. |
| `lsl_bridge.io.serial_utils` | Serial port metadata and startup settling helpers. |
| `lsl_bridge.publishers.reference` | Background RS485 IPC subscriber and reference LSL publisher. |
| `lsl_bridge.publishers.events` | Component event marker outlet. |
| `lsl_bridge.types` | Shared dataclass contracts. |
| `lsl_bridge.logging_setup` | Console/file logging configuration. |

## Serial input path

Target serial data path:

```text
Serial.readline()
  → D2LineParser.feed()
  → ParsedTargetSample
  → TargetTimestampResolver.resolve()
  → SampleTimeResolver.resolve()
  → processor.process()
  → target_outlet.push_sample()
  → TargetCsvSink.write()
```

Design points:

- Overlong target lines are dropped and serial input is flushed.
- Non-D2 lines are dropped and log-throttled.
- Sequence gaps emit `target_sequence_gap` events.
- Metadata frames emit `target_metadata` events.

## IPC input path

Reference IPC path:

```text
ZMQ SUB recv_multipart(NOBLOCK)
  → JSON decode
  → _decode_record()
  → ReferenceSample
  → reference_outlet.push_sample()
  → ReferenceCsvSink.write()
  → status logging / gap events
```

Design points:

- The expected schema is enforced on every IPC message.
- Legacy IPC aliases are not accepted.
- Malformed messages emit `reference_ipc_malformed` events.
- Sequence gaps emit `reference_sequence_gap` events.

## LSL outlets

| Outlet | Builder | Notes |
| --- | --- | --- |
| `HandgripTarget` | `build_target_outlet()` | Target stream metadata includes schema, session ID, firmware metadata, timestamping policy, and calibration signal notes. |
| `HandgripReference` | `build_reference_outlet()` | Reference stream metadata includes schema, session ID, endpoint, nominal rate, and fit signal. |
| `HandgripComponentEvents` | `ComponentEventOutlet` | One JSON string marker per infrastructure event. |

## CSV persistence

CSV sinks write the samples the bridge publishes.

| Sink | File path config | Flush default | Notes |
| --- | --- | --- | --- |
| `TargetCsvSink` | `csv.target.path` | every row | Includes raw line and filtered target value. |
| `ReferenceCsvSink` | `csv.reference.path` | every 25 rows | Includes reference mode, signal key, timestamp source, configured frequency, session ID. |

By default (`write_mode: timestamped`), each run writes to a fresh file with `_<YYYYMMDD_HHMMSS>` inserted before the extension of `csv.*.path`, using one timestamp shared between both sinks. `overwrite` and `append` modes are also available — see [LSL_Bridge/docs/configuration.md](configuration.md).

CSV persistence is useful for debugging. Calibration workflows should still use dedicated calibration session recordings when available.

## Processing path

Current processing:

- input: `target_current_units`,
- processor: `butterworth_lowpass_2nd`,
- output: `target_filtered_units`,
- default cutoff: `9 Hz`,
- filter-domain time source: `device_clock_us`.

Important boundary:

> `target_filtered_units` is a display/QA channel unless a future validated workflow explicitly promotes it. Calibration should preserve and fit `target_raw_count`.

## Failure isolation

| Failure | Likely module |
| --- | --- |
| target serial port cannot open | `app.py`, OS serial permissions, config `serial.port` |
| D2 lines dropped | `core/parser.py`, firmware serial output, `protocol` config  |
| reference missing | `publishers/reference.py`, RS485 GUI IPC, config `rs485_ipc` |
| no LSL streams | `io/lsl_outlets.py`, pylsl runtime, app lifecycle |
| CSV missing | `io/csv_sinks.py`, `csv.*.enabled`, path permissions |
| growing XY delay | `core/timestamping.py`, viewer alignment, device-clock drift |
| filtered signal unstable | `core/filter.py`, processing config, input cadence |

## Validation commands

```bash
uv run pytest tests/unit/test_parser.py
uv run pytest tests/unit/test_timestamping.py
uv run pytest tests/unit/test_filter.py
uv run pytest tests/integration/test_csv_sinks.py
```

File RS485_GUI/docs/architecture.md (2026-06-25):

# RS485 GUI Architecture

## Summary

- `RS485_GUI` is organized as a decoupled acquisition application: pure core helpers, transport implementations, side-effect IO, UI rendering, configuration loading, and a worker thread.
- `MeasurementFrame` is the central data object flowing through transport → worker → state → logger/publisher/UI.
- The GUI should own reference-board parsing and IPC publication, but it should not publish LSL streams directly.
- The source layout is intentionally split so parser logic, UI, logging, and transport can be tested independently.

## Runtime dataflow

```text
config/config.yaml + CLI overrides
  ↓
config.loader.load_app_config()
  ↓
app.run_app() / app.main()
  ↓
AppState + RuntimeSettings
  ↓
connect_state()
  ├── SignalFileLogger.open()
  ├── BoardTransport.connect()
  ├── MeasurementFramePublisher.start()
  └── acquisition_worker thread
        ↓
      transport.read_frames()
        ↓
      list[MeasurementFrame]
        ├── full-rate logger.write_frames()
        ├── full-rate publisher.publish_frames()
        └── display-filtered AppState.push_frames()
              ↓
            NiceGUI / Plotly UI refresh
```

## Source tree

```text
RS485_GUI/src/rs485_gui/
├── app.py
├── worker.py
├── state.py
├── models.py
├── constants.py
├── core/
│   ├── codec.py
│   ├── ports.py
│   ├── sampling.py
│   └── signals.py
├── transport/
│   ├── base.py
│   ├── modbus.py
│   └── active_send.py
├── io/
│   ├── logger.py
│   └── publisher.py
├── ui/
│   ├── layout.py
│   ├── plots.py
│   └── refresh.py
└── config/
    ├── loader.py
    └── schema.py
```

## Layer responsibilities

| Layer | Files | Responsibility | Should not do |
| --- | --- | --- | --- |
| Entry/app | `app.py`, `__main__.py` | Compose config, state, UI, logger, publisher, transport, worker. | Decode low-level frame fields directly. |
| Worker | `worker.py` | Run acquisition loop, rate-limit acquisition/display, dispatch frames. | Own parser details or UI layout. |
| State | `state.py`, `models.py` | Hold runtime settings and frame buffers; define DTOs. | Perform serial IO. |
| Core | `core/*.py` | Pure functions: CRC, register decode, signal extraction, sampling stats, port scoring. | Bind serial ports, files, ZMQ, or UI. |
| Transport | `transport/*.py` | Board IO: Modbus polling and Active-Send parsing. | Render UI or write logs directly. |
| IO | `io/logger.py`, `io/publisher.py` | File logs and ZMQ IPC. | Decode board frames. |
| UI | `ui/*.py` | NiceGUI layout, Plotly figures, refresh callbacks. | Own acquisition semantics. |
| Config | `config/*.py`, `config/config.yaml` | Load config and schema defaults. | Start global Hydra runtime. |

## `MeasurementFrame`

The central data unit is `MeasurementFrame`:

| Field | Meaning |
| --- | --- |
| `host_ts` | Host timestamp as epoch seconds. |
| `host_ts_iso` | Human-readable timestamp. |
| `mode` | `active_send` or `modbus_rtu`. |
| `raw_transport` | Wire/register/diagnostic data. |
| `interpreted` | Decoded engineering values and metadata. |
| `session_id` | Active session ID if configured. |
| `board_profile` | Runtime board/profile snapshot. |

Consumers:

| Consumer | Uses |
| --- | --- |
| `SignalFileLogger` | `raw_transport`, `interpreted`, timestamps, session ID. |
| `MeasurementFramePublisher` | `interpreted` selected signal and canonical aliases. |
| UI plots | selected signal from `interpreted`. |
| Sampling stats | frame timestamps. |

## Transport architecture

### Modbus RTU transport

File:

```text
src/rs485_gui/transport/modbus.py
```

Responsibilities:

- open configured serial port,
- perform Modbus register reads,
- decode 11-register payload,
- send board commands where supported,
- assign host/LSL receive timestamps.

### Active-Send transport

File:

```text
src/rs485_gui/transport/active_send.py
```

Responsibilities:

- read binary push frames from serial stream,
- detect frame boundaries,
- validate CRC,
- decode 11-register Modbus-style response payload,
- reconstruct timestamps using the configured timestamp policy,
- recover from stale-buffer / CRC-resync cascades.

## IO architecture

### File logger

File:

```text
src/rs485_gui/io/logger.py
```

Writes:

- `raw_signal.ndjson`,
- `interpreted_signal.ndjson`,
- `gui_signal.csv`,
- `event.log`.

### IPC publisher

File:

```text
src/rs485_gui/io/publisher.py
```

Publishes:

- measurement topic `rs485.measurement.v1`,
- event topic `rs485.event.v1`.

Important behavior:

- ZMQ bind is lazy and usually happens on connect, not app construction.
- Publication is best-effort by default to avoid blocking acquisition.
- The record includes canonical bridge aliases such as `reference_force_N`.

## UI architecture

| File | Responsibility |
| --- | --- |
| `ui/layout.py`  | Page construction and controls. |
| `ui/plots.py` | Plotly figure construction. |
| `ui/refresh.py` | Periodic UI refresh logic. |

Display-only throttling happens before UI state updates. It should not affect file logs or IPC when calibration-safe defaults are used.

## Configuration architecture

`load_app_config()`:

1. loads `RS485_GUI/config/config.yaml`,
2. applies CLI dotlist overrides,
3. configures logging exactly once,
4. avoids `@hydra.main` since this app is a simple CLI/script entry point, not a Hydra-managed run.

The dataclass schema in `config/schema.py` is documentation/validation support, not the runtime Hydra singleton.

## Extension principles

- Add new board decode fields in `core/codec.py` or transport decode code, not UI first.
- Register new plot signals in `core/signals.py`.
- Expose new persisted fields in `io/logger.py`.
- Expose bridge-required fields in `io/publisher.py` and update [RS485_GUI/docs/ipc-schema.md](ipc-schema.md).
- Add UI controls in `ui/layout.py` and refresh behavior in `ui/refresh.py`.
- Add tests in the smallest layer that owns the behavior.

## Validation map

| Change | Tests/docs to update |
| --- | --- |
| Register decode | `tests/unit/test_codec.py`, [RS485_GUI/docs/active-send-and-modbus.md](active-send-and-modbus.md). |
| Signal registry | `tests/unit/test_signals.py`, [RS485_GUI/docs/configuration.md](configuration.md). |
| File logging | `tests/integration/test_file_logger.py`, [RS485_GUI/docs/logging-and-outputs.md](logging-and-outputs.md). |
| IPC payload | publisher tests/bridge tests where available, [RS485_GUI/docs/ipc-schema.md](ipc-schema.md), root stream contracts. |
| Active-Send parser | `tests/integration/test_active_send_parser.py`, [RS485_GUI/docs/active-send-and-modbus.md](active-send-and-modbus.md). |
| Config key | `tests/unit/test_config.py`, [RS485_GUI/docs/configuration.md](configuration.md). |

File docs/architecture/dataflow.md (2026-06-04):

# Handgrip Suite Dataflow

## Summary

- The Handgrip Suite has two acquisition paths: the **target path** from the Arduino/HX711 handgrip firmware, and the **reference path** from the PM58 load cell through the RS485 acquisition board.
- `RS485_GUI` owns reference-board acquisition and publishes reference measurements over ZeroMQ IPC.
- `LSL_Bridge` owns canonical Lab Streaming Layer (LSL) stream publication for both target and reference data.
- `LSL_Viewer`, `Handgrip_Calibration`, and `Handgrip_Analysis` are downstream consumers; they should not directly reinterpret low-level hardware protocols unless explicitly designed to do so.
- The most important data contract is that the firmware emits `D2,<seq>,<timestamp_us>,<raw_count>,<current_units>,<status>` and the bridge converts that into the `HandgripTarget` LSL stream.

## Dataflow at a glance

```text
Physical force applied to handgrip fixture
│
├── Target chain
│   ├── Handgrip load cell / strain-gauge bridge
│   ├── HX711 ADC
│   ├── Arduino Nano firmware
│   ├── USB UART serial frames: M2 metadata + D2 samples
│   └── LSL_Bridge target serial reader
│       └── LSL stream: HandgripTarget
│
└── Reference chain
    ├── PM58 reference load cell
    ├── High-speed acquisition instrument / board
    ├── RS485 physical link through USB-RS485 adapter
    ├── RS485_GUI acquisition process
    ├── ZeroMQ IPC topic: rs485.measurement.v1
    └── LSL_Bridge reference IPC subscriber
        └── LSL stream: HandgripReference

HandgripTarget + HandgripReference + events
│
├── LSL_Viewer: live plots, XY correlation, replay visualization
├── Handgrip_Calibration: preflight, record, fit, report, validate holdout
└── Handgrip_Analysis: offline analysis stages and filter design
```

## Ownership boundaries

| Boundary | Producer | Consumer | Contract |
| --- | --- | --- | --- |
| Firmware UART | `Handgrip_Firmware` | `LSL_Bridge` | `M2` metadata and `D2` sample lines. |
| RS485 board link | acquisition board | `RS485_GUI` | Active-Send or Modbus RTU measurement frames. |
| Reference IPC | `RS485_GUI` | `LSL_Bridge` | ZMQ topic `rs485.measurement.v1`. |
| LSL streams | `LSL_Bridge` | Viewer/calibration/recording tools | Stream names, channel labels, timestamps, nominal rates. |
| Calibration session folder | `Handgrip_Calibration` | Reports, users, analysis tools | `target.csv`, `reference.csv`, event logs, fit/report files. |
| Analysis output folder | `Handgrip_Analysis` | Users and maintainers | Stage reports, plots, metrics, filter recommendation files.  |

## Target chain details

### Physical source

The target chain is the handgrip device under calibration. Its output is treated as the signal that must be mapped to physical force.

### Firmware source of truth

The firmware should emit:

```text
M2,<payload_schema>,<firmware_version>,<git_sha>,<expected_rate_hz>,<scale_factor>,<scale_offset>,<unit>
D2,<seq>,<timestamp_us>,<raw_count>,<current_units>,<status>
```

The `raw_count` field is the calibration-authoritative value. `current_units` is useful for operator feedback but should not be treated as the primary fit target unless the calibration workflow explicitly says so.

### Bridge transformation

`LSL_Bridge` parses the D2 line and publishes `HandgripTarget`. It should preserve enough metadata to diagnose dropped samples, invalid scale conversion, timestamp gaps, and parser failures.

## Reference chain details

### Physical source

The reference chain is PM58 load cell → acquisition board. It should be mechanically in the same force path as the target handgrip during calibration.

### Acquisition path

The board can be read by `RS485_GUI` through:

- **Active-Send mode** for high-rate push measurements.
- **Modbus RTU polling** as the documented fallback path 

For calibration and production measurement, the preferred reference profile is **Active-Send** because OS-level serial drivers and USB-RS485 adapters may introduce unpredictable latency/jitter that breaks the timing contract, and introduce frequency artifacts on the signal.

### IPC transformation

`RS485_GUI` publishes normalized measurement events to `LSL_Bridge` over ZeroMQ. The bridge should be the only component that translates that IPC stream into the canonical `HandgripReference` LSL stream.

## Downstream consumers

| Consumer | Inputs | Outputs | Main use |
| --- | --- | --- | --- |
| `LSL_Viewer` | `HandgripTarget`, `HandgripReference`, optional marker/event streams | Browser visualization | Validate live signals and timing behavior. |
| `Handgrip_Calibration` | target/reference LSL streams and markers | Calibration session folder + reports | Fit target raw counts to reference force. |
| `Handgrip_Analysis` | CSV/session/manifest inputs | Stage reports and filter recommendations | Offline signal characterization and DSP decisions. |

## Related docs:
- [docs/system-overview.md](../system-overview.md), 
- [docs/architecture/stream-contracts.md](stream-contracts.md), 
- [docs/workflows/full-live-viewer-quickstart.md](../workflows/full-live-viewer-quickstart.md)

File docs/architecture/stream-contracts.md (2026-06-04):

# Stream and Data Contracts

## Summary

- This document is the system-level **map** of cross-component data contracts in the Handgrip Suite.
- Each contract is owned and documented in full by the component that produces it; this page only shows who produces what and links down to the authoritative definition.
- The runtime boundary is `LSL_Bridge`, which converts firmware UART and RS485 GUI IPC into canonical Lab Streaming Layer (LSL) streams consumed by the viewer, calibration, and analysis workflows.

## Contract map

```mermaid
flowchart TD
    FW["Arduino/HX711\ntarget firmware"]
    FW -->|"UART 115200 8N1\nM2 metadata line\nD2 data lines"| LB_T["LSL_Bridge\ntarget parser"]
    LB_T -->|"LSL stream"| HT(["HandgripTarget"])

    PM58["PM58 +\nacquisition board"]
    PM58 -->|"RS485 / USB-RS485"| RS["RS485_GUI"]
    RS -->|"ZeroMQ topic:\nrs485.measurement.v1"| LB_R["LSL_Bridge\nreference IPC subscriber"]
    LB_R -->|"LSL stream"| HR(["HandgripReference"])

    CAL["Handgrip_Calibration"]
    CAL -->|"calibration protocol\nmarker events"| CM(["HandgripCalibrationMarkers\n/ events.ndjson"])

    HT & HR & CM --> CONSUMERS

    subgraph CONSUMERS["LSL streams and session artifacts"]
        VW["LSL_Viewer"]
        HC["Handgrip_Calibration"]
        XDF["XDF / CSV recording\nworkflows"]
        HA["Handgrip_Analysis\n/ report workflows"]
    end
```

## Where each contract is defined

| Contract | Producer / owner | Canonical definition |
| --- | --- | --- |
| Firmware UART frames (`M2` metadata, `D2` data) | `Handgrip_Firmware` | [Handgrip_Firmware/docs/serial-protocol.md](../../Handgrip_Firmware/docs/serial-protocol.md) |
| Acquisition modes behind the reference chain (Active-Send / Modbus RTU) | `RS485_GUI` | [RS485_GUI/docs/active-send-and-modbus.md](../../RS485_GUI/docs/active-send-and-modbus.md) |
| RS485 IPC payload (`rs485.measurement.v1`, `rs485.event.v1`) | `RS485_GUI` | [RS485_GUI/docs/ipc-schema.md](../../RS485_GUI/docs/ipc-schema.md) |
| LSL streams `HandgripTarget` / `HandgripReference` / `HandgripComponentEvents`, channel order, and CSV field order | `LSL_Bridge` | [LSL_Bridge/docs/stream-contracts.md](../../LSL_Bridge/docs/stream-contracts.md) |
| Timestamping / synchronization policy for the LSL streams | `LSL_Bridge` | [LSL_Bridge/docs/timestamping.md](../../LSL_Bridge/docs/timestamping.md) |
| `HandgripCalibrationMarkers` and session artifacts (`target.csv`, `reference.csv`, `events.ndjson`, configs, fit/report files) | `Handgrip_Calibration` | [Handgrip_Calibration/docs/recording.md](../../Handgrip_Calibration/docs/recording.md), [Handgrip_Calibration/docs/reports-and-outputs.md](../../Handgrip_Calibration/docs/reports-and-outputs.md) |
| Which captured fields analysis requires | `Handgrip_Analysis` | [Handgrip_Analysis/docs/workflow.md](../../Handgrip_Analysis/docs/workflow.md) |

## Calibration-authoritative signal

Calibration fits reference force against the raw target count, not firmware-scaled values:

```text
reference_force_N = f(target_raw_count)
```

`target_raw_count` is the HX711 raw ADC count emitted before any firmware scale/offset, which is why it — not `target_current_units` or `target_filtered_units` — is authoritative. The rationale lives with the producers: [Handgrip_Firmware/docs/serial-protocol.md](../../Handgrip_Firmware/docs/serial-protocol.md) and [LSL_Bridge/docs/stream-contracts.md](../../LSL_Bridge/docs/stream-contracts.md).

## Data ownership boundaries

| Contract area | Owner | System invariant |
| --- | ----- | --- |
| Firmware serial schema | `Handgrip_Firmware` | Must emit the current `M2`/`D2` schema. |
| Reference acquisition IPC | `RS485_GUI` | Must publish normalized reference measurements on `rs485.measurement.v1`. |
| Target LSL stream | `LSL_Bridge` | Must expose target raw count and timing metadata. |
| Reference LSL stream | `LSL_Bridge` | Must expose reference force suitable for calibration. |
| Calibration markers / artifacts | `Handgrip_Calibration` | Must preserve protocol boundaries and session inputs for fitting and validation. |
| Viewer rendering | `LSL_Viewer` | Must consume contracts; display settings must not redefine data semantics. |
| Analysis inputs | `Handgrip_Analysis` | Must document which captured fields are required. |

## Change-control rule

Any change to a stream name, channel name or order, firmware frame field, IPC topic/field, reference-force semantic field, calibration-authoritative signal, or consumed session artifact is a cross-component migration. The owning component doc (linked above) lists the exact code, config, and tests that must change together — update this map at the same time.

## End-to-end validation

To confirm all contracts line up at runtime, follow [docs/workflows/full-live-viewer-quickstart.md](../workflows/full-live-viewer-quickstart.md) and the calibration preflight in [Handgrip_Calibration/docs/workflow.md](../../Handgrip_Calibration/docs/workflow.md).

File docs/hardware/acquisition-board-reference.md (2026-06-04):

---
title: High-Speed Acquisition Instrument Reference
status: canonical-reference
last-reviewed: 2026-05-15
---

> **Canonical status:** This is the canonical acquisition-board reference for the Handgrip Suite handoff documentation.
>
> **How to use:** Start here when you need the full menu map, board terminal map, RS485/Modbus/Active-Send options, analog output details, fault messages, or safety boundaries.
>
> **Fallback references:** Source PDFs are under `docs/hardware/references/acquisition-board/`.
>

# High-Speed Acquisition Instrument  
## Reorganized Markdown Manual for the 96×48 Dual-Display Load-Cell Indicator / Transmitter

## Fast navigation

| Need | Go to |
| --- | --- |
| Wire the board safely | [Safety and installation boundaries](#2-safety-and-installation-boundaries), [Rear terminals and wiring map](#6-rear-terminals-and-wiring-map) |
| Understand acquisition-board capabilities | [Product identity and scope](#1-product-identity-and-scope), [Technical specifications](#3-technical-specifications) |
| Configure RS485 / Active-Send | [`C5.CoM` — RS485 communication](#14-c5com--rs485-communication) |
| Configure PM58 calibration on the board | [`C2.CAL` — Calibration](#11-c2cal--calibration) |
| Interpret error messages | [Faults and status messages](#20-faults-and-status-messages) |

---

## Visual and PDF reference set

| Reference | Preview / link | Use it for |
| --- | --- | --- |
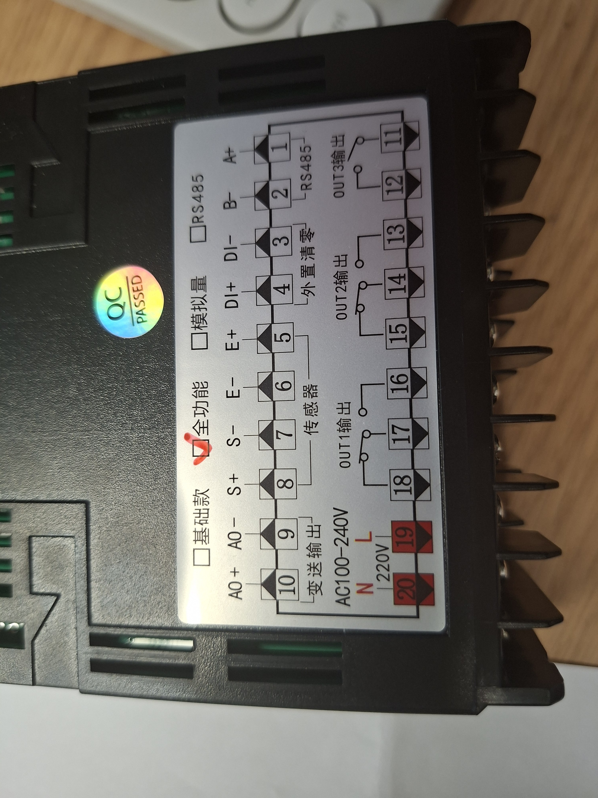
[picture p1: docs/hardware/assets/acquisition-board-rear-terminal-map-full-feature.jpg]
Rear terminal map of the full-feature acquisition board
| Rear terminal map | <br>[Open image](assets/acquisition-board-rear-terminal-map-full-feature.jpg) | Terminal numbering and board-option confirmation. |
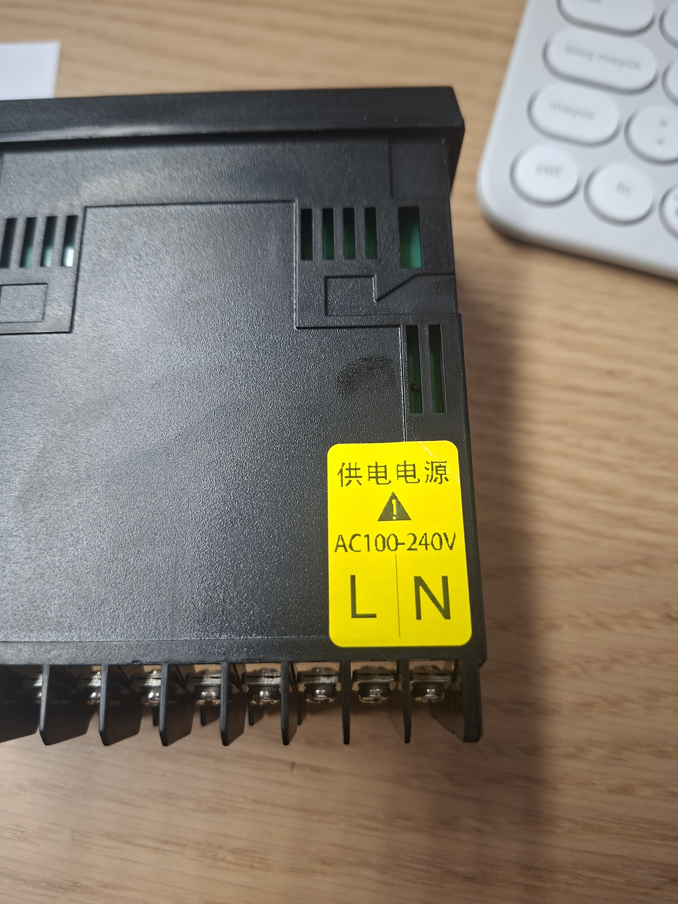
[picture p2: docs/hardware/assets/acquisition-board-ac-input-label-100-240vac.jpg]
AC input label showing AC100-240V, L, and N
| AC input label | <br>[Open image](assets/acquisition-board-ac-input-label-100-240vac.jpg) | Confirms this observed unit is the AC-powered variant. |
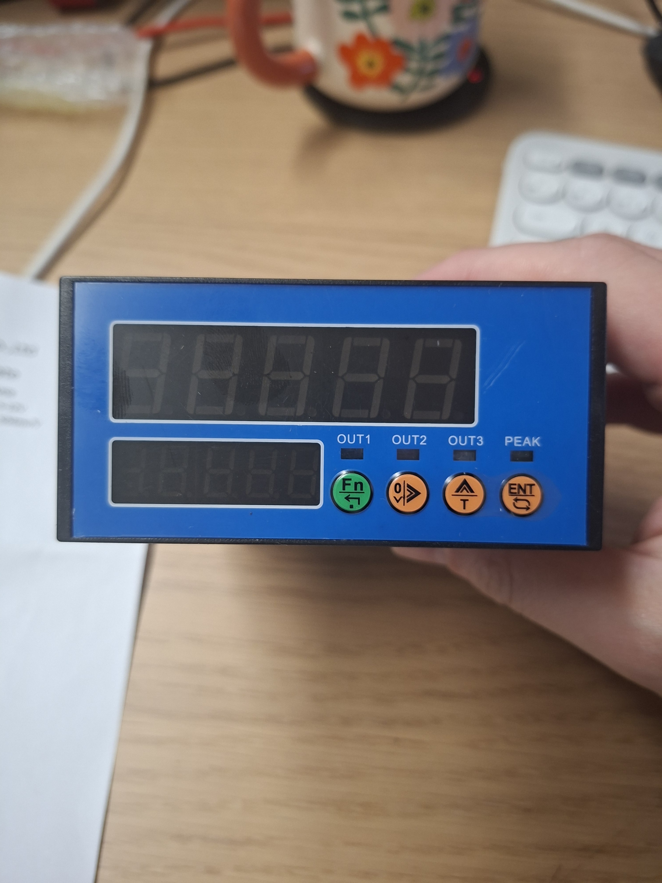
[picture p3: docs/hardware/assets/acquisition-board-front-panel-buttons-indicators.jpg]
Acquisition board front panel with buttons and indicators
| Front panel | <br>[Open image](assets/acquisition-board-front-panel-buttons-indicators.jpg) | Menu navigation and status indicator mapping. |
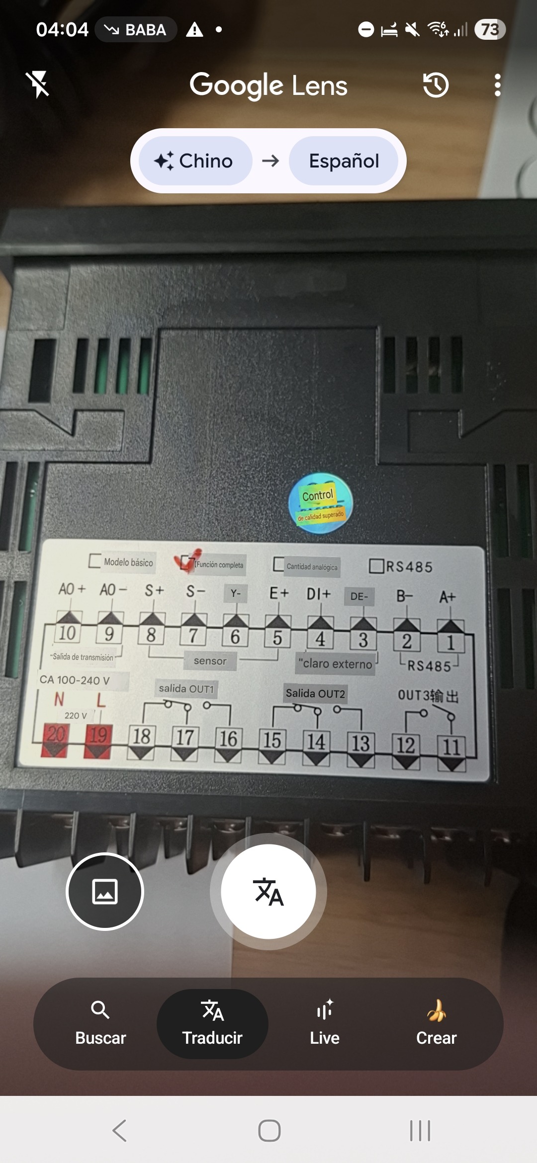
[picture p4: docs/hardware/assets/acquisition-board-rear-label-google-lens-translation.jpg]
Google Lens translated rear label
| Translated rear label | <br>[Open image](assets/acquisition-board-rear-label-google-lens-translation.jpg) | Quick human-readable cross-check of the rear label. |

### Local PDF references

| PDF | Use it for |
| --- | --- |
| [Original acquisition-board manual](references/acquisition-board/acquisition-board-instruction-manual-original-v3.pdf) | Source-level terminal/menu reference. |
| [Machine-translated English acquisition-board manual](references/acquisition-board/acquisition-board-instruction-manual-machine-translated-en-v3.pdf) | English fallback when checking menu names or fault messages. |
| [Provider offer / product-page capture](references/acquisition-board/acquisition-board-provider-offer-screencapture-2026-04-08.pdf) | Product-variant/provenance context. |

## 1. Product identity and scope

This instrument is a **panel-mount load-cell indicator / transmitter / controller** with:
- dual 5-digit LED displays,
- 1 load-cell input,
- up to 3 relay outputs,
- optional analog output,
- optional RS485,
- optional external digital-input trigger / remote zero-tare input.

The PDF describes four variants:

| Variant | Included features |
| --- | --- |
| Basic model | Dual display, 3 relay outputs, 1 digital input |
| Analog-output model | Basic model + analog output |
| RS485 model | Basic model + RS485 |
| Full-function model | Basic model + analog output + RS485 |

### Your observed unit
From the rear label and photos, your unit appears to be the **full-function AC-powered model**, with:
- **AC mains input on terminals 19/20**
- **RS485 on terminals 1/2**
- **Analog output on terminals 9/10**
- **Sensor input on terminals 5/6/7/8**
- **External DI on terminals 3/4**
- **Relay outputs on terminals 11–18**

---

## 2. Safety and installation boundaries

1. Use the unit only within its electrical and environmental ratings.
2. Do not open the chassis while powered.
3. If using the AC-powered version, treat terminals `19/20` as mains-voltage terminals.
4. The manual calls for **reliable grounding** and says the grounding scheme should be kept separate from the AC grounding wire. The unit does **not** document a dedicated PE terminal on the terminal block; treat cabinet grounding as a **system-level installation decision**, not as “tie PE to any negative signal terminal.”
5. Keep sensor wiring away from mains and relay wiring.
6. For noisy environments, prefer:
   - twisted pair for sensor signal lines,
   - shielded cable for RS485,
   - separate routing of sensor and AC power wiring.

---

## 3. Technical specifications

| Item | Value |
| --- | --- |
| Display | Dual 5-digit LED display |
| Supply | `DC 10–28 V` **or** `AC 85–265 V` (rated `100–240 V`, `50/60 Hz`) depending on version |
| Sensor capacity | Up to 8 × `350 Ω` sensors |
| Input signal range | `0.5–3.0 mV/V` |
| Excitation voltage | `5 V` |
| Sampling rates | `10`, `40`, `640`, `1280 Hz` |
| Internal ADC | `24-bit Σ-Δ ADC` |
| Internal resolution | `1 / 1,000,000` |
| Display resolution | `1 / 100,000` |
| Nonlinearity | `0.005 %FS` |
| Max power consumption | `5 W` |
| Operating temperature | `-25 °C` to `+45 °C` |
| Relative humidity | `< 85 %RH` |
| Approx. weight | `300 g` |
| External size | `96 × 48 × 110 mm` |
| Panel cutout | `92 × 46 mm` |

### Practical meaning of the 4 sampling rates
The manual lists `10 / 40 / 640 / 1280 Hz` but does not explain the tradeoff well. Similar weighing-indicator manuals with the same rate set explain the general rule:

- **Higher sampling rate** → faster response, lower effective noise immunity / less stable display
- **Lower sampling rate** → slower response, better stability

That matches the rest of this board’s menu structure because it also provides median and averaging filters.

---

## 4. Mechanical installation

- Front panel format: **96 × 48 mm**
- Panel cutout: **92 × 46 mm**
- Insert the instrument from the front of the panel.
- Use the included metal rear clamps / brackets to secure it from the back.

### Included mounting clamps
The loose metal parts shipped with the unit are **panel-mount brackets for the display unit**, not load-cell mounting hardware.

---

## 5. Front panel and user interface

### 5.1 Display behavior

- **Main display:** net weight
- **Secondary display:** setting parameter, gross weight, peak value, or unit

### 5.2 Indicators

| Indicator | Meaning |
| --- | --- |
| `OUT1`, `OUT2`, `OUT3` | Corresponding relay output is active |
| `PEAK` solid | Secondary display is currently showing peak value |
| `PEAK` flashing | Waiting for peak-trigger condition |

### 5.3 Keys

The source PDF shows icon-only legends. On your front-panel photo, the practical mapping is:

| Key position | Practical name | Short press | Long press |
| --- | --- | --- | --- |
| Green `Fn` key | Menu / back | Enter menu or return to previous level | Enter decimal-point selection |
| First orange key (down-arrow / calibration icon) | Calibration / cursor down | Enter calibration interface or move down / move cursor | Zero function |
| Second orange key (up-arrow / `T`) | Up / increment / tare | Change menu item / increment value | Tare |
| Orange `ENT` key | Confirm / display switch  | Confirm in menu; in display mode cycle secondary display (unit / gross / peak) | Clear peak |

> **Important note:** The key semantics above are directly supported by the PDF, but the exact symbol-to-key mapping is partly reconstructed from your front-panel photo because the machine-translated PDF drops some icons.

---

## 6. Rear terminals and wiring map

### 6.1 Terminal assignment for the full-function model observed in your photos

| Terminal | Label  | Purpose |
| --- | --- | --- |
| 1 | `A+` | RS485 `A` / non-inverting line |
| 2 | `B-` | RS485 `B` / inverting line |
| 3 | `DI-`  | External digital input / remote zero-tare return |
| 4 | `DI+`  | External digital input / remote zero-tare input  |
| 5 | `E+` | Sensor excitation + |
| 6 | `E-` | Sensor excitation - |
| 7 | `S-` | Sensor signal - |
| 8 | `S+` | Sensor signal + |
| 9 | `AO-`  | Analog output - |
| 10 | `AO+`  | Analog output + |
| 11–12 | `OUT3` | Relay output 3 dry contact |
| 13–15 | `OUT2` | Relay output 2 dry contact set |
| 16–18 | `OUT1` | Relay output 1 dry contact set |
| 19 | `L` | AC live |
| 20 | `N` | AC neutral |

### 6.2 Power terminals

The manual says terminals 19 and 20 are the power input:
- **DC version:** `DC+ / DC-`
- **AC version:** `N / L`

Your board label explicitly shows **AC100–240V** and `L/N`, so your unit should be treated as the AC version.

### 6.3 Sensor input terminals

The manual defines:
- `S+` = sensor signal +
- `S-` = sensor signal -
- `E+` = excitation +
- `E-` = excitation -

### 6.4 External digital input

Shorting the DI input can trigger a selectable remote function:
- temporary tare
- saved tare
- cancel tare
- temporary zero
- saved zero calibration
- clear peak  
This function is configured by menu parameter `109.di`.

### 6.5 Relay outputs

The manual states all outputs are **passive dry contacts**. The rear legend shows:
- `OUT1`: 3-terminal relay contact set
- `OUT2`: 3-terminal relay contact set
- `OUT3`: 2-terminal contact pair on the observed label

Because the PDF does not explicitly label `COM / NO / NC` in text, **verify contact state with a multimeter before wiring an external load**.

### 6.6 Analog output

Optional analog output supports:
- `0–20 mA`
- `4–20 mA`
- `4–12–20 mA`
- `0–3.3 V`
- `0–5 V`
- `0–10 V`
- `0–5–10 V`

### 6.7 RS485

Optional RS485 uses **Modbus-RTU** and supports:
- addressed communication,
- configurable baud / parity / stop bits,
- an “active send” mode,
- configured send frequencies up to `1000 Hz` per menu definition.

---

## 7. Quick-start workflow

1. **Install the unit mechanically** in the panel cutout.
2. **Wire power** according to the actual board version.
3. **Wire the sensor** to `E+ / E- / S+ / S-`.
4. **Power on** and verify the display exits the `PoiNt` startup state.
5. **Zero the system** with no load.
6. **Perform calibration**:
   - either with a real applied load (`Load` mode),
   - or by entering sensor sensitivity / range (`data` mode).
7. Configure optional:
   - relay outputs,
   - analog output,
   - RS485.
8. Validate:
   - zero,
   - tare,
   - span,
   - overload,
   - communications / output scaling.

---

## 8. Normal operating actions

## 8.1 Zero

### Purpose
Set the current no-load reading to zero.

### How to do it
1. Remove the load from the sensor.
2. Wait until the reading is stable.
3. Long-press the **Calibration/Down** key to enter the zero action.
4. Confirm if prompted.

### Constraints
- Zero will only be accepted if the current absolute reading is within the configured `405.Zr` zero range.
- If zero fails, you may see `AL.MZr`.

---

## 8.2 Tare

### Purpose
Subtract the current applied offset load so the displayed net value becomes zero.

### How to do it
1. Place the tare load on the sensor.
2. Wait until the reading is stable.
3. Long-press the **Up / Tare** key.
4. The display should switch to net-zero behavior.

### Clearing tare
Use either:
- the configured DI action `CPEEL`, or
- menu action / re-zero workflow depending on your setup.

### Constraints
- If tare conditions are not met, the instrument may show `AL.PEL`.

---

## 8.3 Cycle the secondary display

### Purpose
Change what the lower display shows.

### How to do it
1. In normal measurement mode, short-press **ENT**.
2. Cycle through:
   - unit,
   - gross,
   - peak.

The default secondary-display item is set by `104.ds`.

---

## 8.4 Peak display and clear peak

### Purpose
Capture and display peak value behavior.

### How to use
1. Enable / tune peak behavior using:
   - `110.MZ` peak threshold
   - `111.MN` peak detection interval
2. Use **ENT** to switch the secondary display to peak.
3. Long-press **ENT** to clear the stored peak value.

---

## 9. Menu structure overview

| Main menu | Purpose |
| --- | --- |
| `C1.SyS`  | System settings |
| `C2.CAL`  | Calibration settings |
| `C3.rEL`  | Relay output configuration |
| `C4.AdV`  | Advanced application behavior |
| `C5.CoM`  | RS485 communication |
| `C6.aNa`  | Analog output |
| `C7.LOC`  | Login password |
| `C8.FAC`  | Factory calibration |
| `C9.iNF`  | Version / device info |

---

## 10. `C1.SyS` — System settings

| Code | Name | Default | Range | Purpose / notes |
| --- | --- | ---: | --- | --- |
| `100.SP` | Sampling rate | `40H` | `10, 40, 640, 1280 Hz` | Select acquisition/update speed |
| `101.GA` | Gain adjustment |  `128B` | `1, 2, 64, 128B` | ADC gain selection |
| `102.ME` | Median filtering | `5` | `1, 3, 5, 9` | Median of N samples |
| `103.rV` | Average filtering | `5` | `1–50` | Larger value = more stable, slower response |
| `104.ds` | Secondary display default |  `uNit` | `0:Gross, 1:Peak, 2:Unit` | Lower display default item |
| `105.uN` | Unit selection | `kG` | `0–9` | `NoNE, g, kg, t, N, pa, kPa, MPa, N·m, kN` |
| `106.bi` | Decimal point position | `0` | `0–4` | Display format |
| `107.dV` | Graduation value | `1` | `1,2,5,10,20,50,100` | Display increment / division |
| `108.ro` | Maximum weighing | `99999` | `0–99999` | Over this, display `AL.oL`; must be `≤ total sensor range - tare` |
| `109.di` | DI switch input function  |  `NoNE` | `0–6` | Remote DI behavior |
| `110.MZ` | Peak judgment threshold | `50` | `0–50000` | Threshold to re-arm / refresh peak detection |
| `111.MN` | Peak detection interval | `0.5` | `0–5.000 s` | Minimum interval between peak detections |
| `112.br` | Display brightness | `L5` | `L1–L8` | LED brightness |
| `113.uP` | Display refresh time |  `0.02` | `0.02–1.000 s` | How often displayed value refreshes |
| `114.bp` | Backup parameters | `NO` | `YES/NO` | Store current config and calibration |
| `115.Lp` | Load backup parameters | `NO` | `YES/NO` | Restore previously saved backup |
| `116.FA` | Restore factory settings  | `NO` | `YES/NO` | Factory default reset |

### 10.1 How to configure system settings
1. Press **Fn** to enter the menu.
2. Use **Down** and **Up** to move/select parameters.
3. Press **ENT** to edit / confirm.
4. Use **Fn** to go back.

### 10.2 Recommended starting values
For a single load cell in a lab / bench environment:
- `100.SP = 40 Hz`
- `102.ME = 3 or 5`
- `103.rV = 5–10`
- `113.uP = 0.05–0.10 s`

For faster force events / peak capture:
- raise `100.SP` to `640` or `1280 Hz`
- reduce `103.rV`
- tune `110.MZ` and `111.MN`

---

## 11. `C2.CAL` — Calibration

| Code | Name | Default | Range | Purpose |
| --- | --- | ---: | --- | --- |
| `200.ZE` | Zero calibration | — | AD internal code value | Save current zero point |
| `201.Mo` | Calibration mode |  `Load` | `Load / data` | Choose physical-weight or digital-entry calibration |
| `202.WE` | Weight value | — | actual load | Applied reference weight in `Load` mode |
| `203.rA` | Sensor range | — | `10–99999` | Single-sensor range × number of sensors; used in `data` mode |
| `204.SE` | Sensor sensitivity | `2.000` | `0.010–10.000 mV/V` | Enter sensor sensitivity |
| `205.rE` | Sensor excitation voltage | `5` | `0.010–10.000 V` | Excitation level |
| `206.rV` | Range correction factor | `1.000` | `0.010–2.000` | Fine span correction |
| `207.mE` | Multi-point correction enable | `0` | `0:Close, 1:Open` | Turn multipoint correction on/off |
| `208.mC` | Multipoint calibration | — | example-based | Add correction points |
| `209.Mr` | Calibration points | — | — | Number of multipoint-calibration points |

## 11.1 Recommended calibration workflow (load calibration)
This is the most practical method for your PM58 load cell.

1. Mechanically install the sensor.
2. Wire the sensor to `E+ / E- / S+ / S-`.
3. Let the system warm up for a few minutes.
4. Remove all applied load.
5. Enter `C2.CAL`.
6. Run `200.ZE` to save the zero point.
7. Ensure `201.Mo = Load`.
8. Set `202.WE` to the known calibration load you will apply.
9. Apply that known physical load.
10. Confirm the calibration operation when prompted by the UI.
11. Remove and re-apply the load to validate linearity.
12. If span is slightly off, adjust `206.rV`.
13. If needed, enable `207.mE` and use `208.mC` for multipoint correction.

## 11.2 Digital calibration (`data` mode)
Use this when the sensor datasheet is trusted and physical calibration weight is unavailable.

1. Enter `C2.CAL`.
2. Run `200.ZE` with no load.
3. Set `201.Mo = data`.
4. Set `203.rA = single-sensor full-scale × number of sensors`.
5. Set `204.SE = sensor sensitivity (mV/V)`.
6. Set `205.rE = excitation voltage` used by the indicator.
7. Confirm calibration.
8. Validate with one or more real loads anyway; if necessary trim with `206.rV`.

### Example for your PM58
Your PM58 certificate / label shows approximately:
- range: `100 kg`
- sensitivity: about `1.504 mV/V`
- excitation / supply range: `5–12 V`

Because this indicator excites the sensor at `5 V`, a digital calibration starting point would be:
- `203.rA = 100` (or `100000` if your chosen engineering-unit scale is in grams)
- `204.SE ≈ 1.504`
- `205.rE = 5.000`

> Final scaling depends on the unit and decimal-point choices under `C1.SyS`.

## 11.3 When calibration will fail
The instrument can reject calibration if data is unstable. The error code `Er.buy` explicitly says operations like zeroing / calibration may fail when the data has not become stable first.

---

## 12. `C3.rEL` — Relay outputs

Each relay can be configured independently.

| Code | Name | Meaning |
| --- | --- | --- |
| `300.m1` / `306.m2` / `312.m3` | Working mode | Relay behavior |
| `301.V1` / `307.V2` / `313.V3` | Data type | Which measured value drives the relay |
| `302.r1` / `308.r2` / `314.R3` | Return difference / hysteresis | Prevent chatter |
| `303.t1` / `309.t2` / `315.t3` | Action delay | Delay before relay actuation |
| `304.h1` / `310.h2` / `316.h3` | Upper limit | High threshold |
| `305.L1` / `311.L2` / `317.L3` | Lower limit | Low threshold |

### 12.1 Relay working modes
| Value | Mode | Purpose |
| ----- | --- | --- |
| `0` | `NoNE`  | Disabled |
| `1` | `hiGh`  | Activate above upper threshold |
| `2` | `Low` | Activate below lower threshold |
| `3` | `iNraN` | Activate within band |
| `4` | `outrN` | Activate outside band |

### 12.2 Relay data source
| Value | Data source |
| ----- | --- |
| `0` | Gross |
| `1` | Net |
| `2` | Peak |

### 12.3 Example: configure OUT1 as an over-force alarm
1. Enter `C3.rEL`.
2. Set `300.m1 = hiGh`.
3. Set `301.V1 = NEt` (or `GroSS`, depending on your use case).
4. Set `304.h1` to the alarm threshold.
5. Set `302.r1` to a hysteresis value to stop relay chatter.
6. Optionally set `303.t1` for delayed actuation.
7. Save and test.

### 12.4 Example: configure OUT2 as an in-window OK signal
1. Set `306.m2 = iNraN`.
2. Set `307.V2` to the desired data source.
3. Set `311.L2 = lower bound`.
4. Set `310.h2 = upper bound`.
5. Tune `308.r2` and `309.t2`.

---

## 13. `C4.AdV` — Advanced applications

| Code | Name | Default | Range | Purpose |
| --- | --- | ---: | --- | --- |
| `400.CV` | Creep tracking | `0` | `0–10` | Compensate slow drift / creep |
| `401.dZ` | Display zeroing range | `0` | `0–50000` | Display zero while internal value still exists |
| `402.tV` | Dynamic tracking range | `0` | `0–50000` | Dynamic tracking behavior |
| `403.tC` | Dynamic tracking refresh | `0.2` | `0–2.000` | Dynamic-tracking refresh interval |
| `404.SV` | Stable weight switch | `0` | `0–1` | Show only final stable value |
| `405.Zr` | Zero range | `500` | `0–50000` | Allowed manual / automatic zeroing range |
| `406.PZ` | Power-on zero switch | `0` | `0–1` | Enable auto-zero after power-up |
| `407.Pt` | Power-on zero time | `10` | `0–1800 s` | Countdown time after power-up |
| `408.Pr` | Power-on zero range | `50` | `0–50000` | Allowed zero-detection band at startup |
| `409.AZ` | Automatic zero switch | `0` | `0–1` | Background auto-zero enable |
| `410.At` | Automatic zeroing time |  `0.10` | `0.01–9.999 s` | Dwell time for auto-zero |
| `411.Ar` | Automatic zero range (divisions) | `1.0` | `0.1–50.0` | Auto-zero band in divisions |
| `412.Wr` | Stability range (divisions) | `0` | `0–5` | Stable-window threshold |
| `413.Wt` | Stability time | `1.000` | `0.01–9.999 s` | Stable detection time |

### 13.1 Interpreting the advanced features

#### `400.CV` — creep tracking
Use to compensate slow offset drift in the measured value.  
- `0` = disabled  
- higher values = stronger tracking  

#### `401.dZ` — display zeroing range
If the absolute reading is within this range, the display shows zero **but the internal value is not actually reset**.  
Example from the manual:
- actual zero offset = `4`
- `401.dZ = 5`
- display shows `0`
- if you then apply `20`, the display becomes `24`

#### `404.SV` — stable weight switch
When enabled, the display jumps directly to the final stable value instead of visibly ramping through intermediate values.

#### `409.AZ`, `410.At`, `411.Ar`
This is the true **automatic zeroing** function. Unlike `401.dZ`, this one actually pulls the zero point back to zero after the reading stays inside the configured zero band for the configured time.

#### `412.Wr`, `413.Wt`
These define whether the instrument considers the weight **stable**. Stability matters because tare, zero, and calibration acceptance can depend on it.

### 13.2 Recommended starting values for force / bench testing
- `400.CV = 0` initially
- `401.dZ = 0` unless you intentionally want cosmetic zeroing
- `404.SV = 0` for live observation, `1` for operator-facing stable display
- `409.AZ = 0` for dynamic force tests
- `412.Wr = 1` or `2`
- `413.Wt = 0.2–1.0 s`

---

## 14. `C5.CoM` — RS485 communication

| Code | Name | Default | Range | Purpose |
| --- | --- | ---: | --- | --- |
| `500.Ar` | Address | `1` | `1–253` | Modbus slave address |
| `501.br` | Baud rate | `3` | `1–15`  | Baud-rate selection |
| `502.Vb` | Check bit | `0` | `0–2` | Parity |
| `503.so` | Stop bit | `1` | `1/2` | Stop-bit selection |
| `504.AS` | Active sending mode | `0` | `0–1` | `0` = Modbus RTU mode, `1` = active send |
| `505.AF` | Active-send frequency | `2` | `0–9` | `1 Hz` to `1000 Hz` |

### 14.1 Baud-rate codes
| Code | Baud rate |
| ---- | ---: |
| `1`  | `2400` |
| `2`  | `4800` |
| `3`  | `9600` |
| `4`  | `19200` |
| `5`  | `22800` |
| `6`  | `38400` |
| `7`  | `57600` |
| `8`  |  `115200` |
| `9`  |  `128000` |
| `10` |  `230400` |
| `11` |  `256000` |
| `12` |  `460800` |
| `13` |  `500000` |
| `14` |  `512000` |
| `15` |  `600000` |

### 14.2 Parity codes
| Code | Meaning |
| ---- | --- |
| `0`  | none |
| `1`  | even |
| `2`  | odd |

### 14.3 Important UI note
The PDF says baud-rate changes apply immediately, but because the display is short, the UI omits the last two digits when showing the value.  
Examples:
- `2400` may display as `24`
- `115200` may display as `1152`

### 14.4 How to enable Modbus RTU
1. Enter `C5.CoM`.
2. Set `500.Ar` to the device address.
3. Set `501.br`, `502.Vb`, `503.so` to match the host.
4. Set `504.AS = 0` (this means **Modbus RTU**, not active-send mode).
5. Power-cycle / reconnect the host if needed.

### 14.5 How to enable active-send mode
1. Enter `C5.CoM`.
2. Set serial format parameters as needed.
3. Set `504.AS = 1`.
4. Set `505.AF` to the desired push frequency.
5. Validate on the host with a serial capture.

> The PDF confirms that `504.AS = 0` means Modbus-RTU mode, but it does not document the active-send payload format.

---

## 15. `C6.aNa` — Analog output

| Code | Name | Default | Range | Purpose |
| --- | --- | ---: | --- | --- |
| `600.At` | AO output type | `1` | `0–3` | What signal drives AO |
| `601.As` | AO signal type | `0` | `0–1` | Current or voltage |
| `602.ax` | AO maximum weight |  `5000` | `0–99999` | Full-scale mapped value |
| `603.ai` | AO minimum weight | `0` | `0–9999` | Zero-point mapped value |
| `604.aP` | AO minimum-weight polarity | `0` | `0–1` | Positive or negative minimum |
| `605.CL` | Lower current limit | `4` | `0–10.00` | Usually `0` or `4 mA` |
| `606.Ch` | Upper current limit | `20` | `10.00–21.00` | Usually `20 mA` |
| `607.VL` | Lower voltage limit | `0` | `0–5.00` | Usually `0 V` |
| `608.Vh` | Upper voltage limit | `10.00` | `5.00–10.00`  | Usually `5 V` or `10 V` |

### 15.1 AO source selection
| `600.At` value | Source |
| --- | --- |
| `0` | None |
| `1` | Gross  |
| `2` | Net |
| `3` | Peak |

### 15.2 AO signal type
| `601.As` value | Type |
| --- | --- |
| `0` | Current |
| `1` | Voltage |

### 15.3 Supported analog-output modes
The PDF implies the following are obtained by setting the limits appropriately:

#### Current mode
- `0–20 mA` → `605.CL = 0`, `606.Ch = 20`
- `4–20 mA` → `605.CL = 4`, `606.Ch = 20`
- `4–12–20 mA` → use negative minimum polarity and bipolar span arrangement

#### Voltage mode
- `0–5 V` → `607.VL = 0`, `608.Vh = 5`
- `0–10 V` → `607.VL = 0`, `608.Vh = 10`
- `0–5–10 V` → use negative minimum polarity and bipolar span arrangement

### 15.4 How to configure 4–20 mA output
1. Enter `C6.aNa`.
2. Set `600.At` = desired source (`Gross`, `Net`, or `Peak`).
3. Set `601.As = Curr`.
4. Set `603.ai` = minimum engineering value.
5. Set `602.ax` = maximum engineering value.
6. Set `604.aP = plus`.
7. Set `605.CL = 4`.
8. Set `606.Ch = 20`.
9. Measure the output with a meter and validate.

### 15.5 How to configure 0–10 V output
1. Set `600.At` to desired source.
2. Set `601.As = VoLt`.
3. Set `603.ai` = minimum engineering value.
4. Set `602.ax` = maximum engineering value.
5. Set `604.aP = plus`.
6. Set `607.VL = 0`.
7. Set `608.Vh = 10`.
8. Validate using a voltmeter or analog-input card.

### 15.6 Bipolar note
The manual explicitly says that when `604.aP = miNus`, the AO minimum corresponds to a **negative full-scale direction**, enabling midpoint-style output modes such as:
- `4–12–20 mA`
- `0–5–10 V`

---

## 16. `C7.LOC` — Password control

| Code | Name | Default | Range | Purpose |
| --- | --- | ---: | --- | --- |
| `700.oP` | Password switch | `0` | `0–1` | Enable / disable login protection |
| `701.PW` | Change password |  `0000` | `0–9999` | User password |

### How to use
1. Set `700.oP = Open` to require password entry.
2. Use `701.PW` to set a new password.
3. The manual says the existing password must be entered before a new one can be stored.

---

## 17. `C8.FAC` — Factory calibration (reserved)

| Code | Name | Purpose |
| --- | --- | --- |
| `800.Lo` | Manufacturer password | Internal factory access |
| `801.EX` | Exit factory calibration | Leave factory menu |
| `802.01` | AO 0.1 mA calibration | Factory analog calibration |
| `803.4m` | AO 4 mA calibration | Factory analog calibration |
| `804.1O` | AO 10 mA calibration | Factory analog calibration |
| `805.12` | AO 12 mA calibration | Factory analog calibration |
| `806.20` | AO 20 mA calibration | Factory analog calibration |
| `807.UU` | AO 10 V calibration | Factory analog calibration |
| `808.Ad` | ADC benchmark setting | Factory ADC trim |

### Recommendation
Do **not** modify `C8.FAC` unless you are intentionally recalibrating the analog-output stage and have traceable measurement equipment.

---

## 18. `C9.iNF` — Version / identification

| Code | Name | Purpose |
| --- | --- | --- |
| `900.VE` | Software version number | Firmware version  |
| `901.id` | Unique device code | Device identifier |

---

## 19. External DI / remote-trigger behavior

The manual says shorting terminals `3` and `4` can perform a configurable remote action.  
This is chosen by `109.di`:

| Value | Function |
| ----- | --- |
| `0` | None |
| `1` | `tPEEL` — tare, not saved after power loss |
| `2` | `SPEEL` — tare, saved after power loss |
| `3` | `CPEEL` — cancel tare, saved |
| `4` | `SZEro` — zero, not saved after power loss |
| `5` | `CZEro` — zero calibration, saved |
| `6` | `REMAX` — clear peak |

### How to use
1. Set `109.di` to the desired action.
2. Wire a dry contact or switch to `DI+` / `DI-`.
3. Briefly short the input to trigger the action.
4. Confirm behavior before deploying in production.

---

## 20. Faults and status messages

### 20.1 Secondary-display messages

| Code | Meaning |
| --- | --- |
| `PoiNt`  | Power-on initialization; exits after first valid data, or after power-on-zero countdown if enabled |
| `-----`  | No valid peak has been captured |
| `Err.ro` | EEPROM read/write failure |
| `Err.Ad` | ADC fault |
| `AL.Ad`  | ADC overrange / signal too large / max-min ADC code reached |
| `AL.oL`  | Sensor overload or exceeds configured max range |
| `AL.AZR` | Power-on zero failed; outside configured startup zero range |
| `AL.PEL` | Manual tare failed; tare conditions not satisfied |
| `AL.MZr` | Manual zero failed; zero conditions not satisfied |

### 20.2 Main-display messages

| Code | Meaning |
| --- | --- |
| `-----`  | Appears while modifying sampling rate; auto-exits |
| `Er.doM` | Entered value too small; clamped to minimum |
| `Er.up`  | Entered value too large; clamped to maximum |
| `Er.iNV` | Invalid user input |
| `Er.pwE` | Wrong password |
| `FA.roM` | Parameter write failed, but values already took effect |
| `FA.AdC` | ADC setting failed |
| `Er.buy` | Instrument busy; operation attempted before data was stable |

### Troubleshooting guidance
- `AL.Ad` → check sensor wiring, overload, broken cable, wrong excitation/signal wiring, sensor out of range.
- `AL.oL` → reduce load or increase configured max range `108.ro`.
- `AL.AZR` → widen `408.Pr` or fix startup offset.
- `AL.PEL`, `AL.MZr`, `Er.buy` → wait for stability; review `412.Wr` / `413.Wt`, filtering, and mechanical vibration.

---

## 21. Practical configuration recipes

## 21.1 Stable bench scale setup
- `100.SP = 40`
- `102.ME = 5`
- `103.rV = 10`
- `404.SV = 0`
- `409.AZ = 1`
- `410.At = 0.2`
- `411.Ar = 1.0`
- `412.Wr = 1`
- `413.Wt = 0.5`

## 21.2 Fast force / peak capture setup
- `100.SP = 640` or `1280`
- `102.ME = 1` or `3`
- `103.rV = 1–3`
- `110.MZ` = application-dependent
- `111.MN` = small nonzero interval
- `404.SV = 0`
- `409.AZ = 0`

## 21.3 PLC analog-output setup (4–20 mA)
- `600.At = NEt`
- `601.As = Curr`
- `603.ai = minimum process value`
- `602.ax = maximum process value`
- `605.CL = 4`
- `606.Ch = 20`

## 21.4 PLC RS485 / Modbus setup
- `500.Ar = chosen slave address`
- `501.br = 9600` or `115200`
- `502.Vb = none`
- `503.so = 1`
- `504.AS = 0`

---

## 22. Modbus register map

The PDF provides a master/slave Modbus-RTU register map. The table below ports the documented content into a more readable form.

### 22.1 Read-only measurement values

|  Dec | Hex | PLC | Name | Type | Access | Notes |
| ---: | --- | ----: | --- | --- | --- | --- |
| 0 | `0x0000` | 40001 | Total weight low word | 32-bit signed low  | R | Gross / total weight |
| 1 | `0x0001` | 40002 | Total weight high word  | 32-bit signed high | R | Gross / total weight |
| 2 | `0x0002` | 40003 | Net weight low word | 32-bit signed low  | R | Net weight |
| 3 | `0x0003` | 40004 | Net weight high word | 32-bit signed high | R | Net weight |
| 4 | `0x0004` | 40005 | Peak value low word | 32-bit signed low  | R | Peak |
| 5 | `0x0005` | 40006 | Peak value high word | 32-bit signed high | R | Peak |
| 6 | `0x0006` | 40007 | Internal code low word  | 32-bit signed low  | R | ADC internal code |
| 7 | `0x0007` | 40008 | Internal code high word | 32-bit signed high | R | ADC internal code |

### 22.2 Shared configuration / status registers

|  Dec | Hex | PLC | Name | Type | Access | Meaning |
| ---: | --- | ----: | --- | --- | --- | --- |
| 8 | `0x0008` | 40009 | Decimal point | 16-bit unsigned | R/W | `0:00000`, `1:0000.0`, `2:000.00`, `3:00.000`, `4:0.0000` |
| 9 | `0x0009` | 40010 | Unit | 16-bit unsigned | R/W | `0:none`, `1:g`, `2:kg`, `3:t`, `4:N`, `5:pa`, `6:kPa`, `7:MPa`, `8:N·m`, `9:kN` |
| 10 | `0x000A` | 40011 | Status | 16-bit unsigned | R | bit / code-like status item list per manual |
| 11 | `0x000B` | 40012 | Command | 16-bit unsigned | R/W | `1:tare temp`, `2:tare save`, `3:cancel tare`, `4:zero temp`, `5:zero save`, `6:clear peak`, `7:calibration`, `9:factory reset` |
| 12 | `0x000C` | 40013 | Weight value low word | 32-bit signed low  | R/W | calibration weight input |
| 13 | `0x000D` | 40014 | Weight value high word | 32-bit signed high | R/W | calibration weight input |
| 14 | `0x000E` | 40015 | Creep tracking | 16-bit unsigned | R/W | `0–10` |
| 15 | `0x000F` | 40016 | Display zeroing | 16-bit unsigned | R/W | `0–5000` |
| 16 | `0x0010` | 40017 | Dynamic tracking range | 16-bit unsigned | R/W | `0–5000` |
| 17 | `0x0011` | 40018 | Dynamic tracking update time | 16-bit unsigned | R/W | `0–2000 ms` |
| 18 | `0x0012` | 40019 | Stable weight switch | 16-bit unsigned | R/W | `0:off`, `1:on` |
| 19 | `0x0013` | 40020 | Zero range | 16-bit unsigned | R/W | `0–5000` |
| 20 | `0x0014` | 40021 | Power-on zero enable | 16-bit unsigned | R/W | `0:off`, `1:on` |
| 21 | `0x0015` | 40022 | Power-on zero time | 16-bit unsigned | R/W | `0–1800 s` |
| 22 | `0x0016` | 40023 | Power-on zero range | 16-bit unsigned | R/W | `0–50000` |
| 23 | `0x0017` | 40024 | Automatic zero enable | 16-bit unsigned | R/W | `0:off`, `1:on` |
| 24 | `0x0018` | 40025 | Automatic zeroing time | 16-bit unsigned | R/W | `100–9999 ms` |
| 25 | `0x0019` | 40026 | Automatic zero range | 16-bit unsigned | R/W | `10–500` in 0.1-division units |
| 26 | `0x001A` | 40027 | Stable range division | 16-bit unsigned | R/W | `0–5` |
| 27 | `0x001B` | 40028 | Stable time | 16-bit unsigned | R/W | `100–9999 ms` |

### 22.3 Relay 1 registers

|  Dec | Hex | PLC | Name | Type | Access |
| ---: | --- | ----: | --- | --- | --- |
| 28 | `0x001C` | 40029 | Relay 1 working mode | 16-bit unsigned | R/W |
| 29 | `0x001D` | 40030 | Relay 1 hysteresis | 16-bit unsigned | R/W |
| 30 | `0x001E` | 40031 | Relay 1 data type | 16-bit unsigned | R/W |
| 31 | `0x001F` | 40032 | Relay 1 action delay | 16-bit unsigned | R/W |
| 32 | `0x0020` | 40033 | Relay 1 upper limit low word  | 16-bit unsigned low  | R/W |
| 33 | `0x0021` | 40034 | Relay 1 upper limit high word | 16-bit unsigned high | R/W |
| 34 | `0x0022` | 40035 | Relay 1 lower limit low word  | 16-bit unsigned low  | R/W |
| 35 | `0x0023` | 40036 | Relay 1 lower limit high word | 16-bit unsigned high | R/W |

### 22.4 Relay 2 registers

|  Dec | Hex | PLC | Name | Type | Access |
| ---: | --- | ----: | --- | --- | --- |
| 36 | `0x0024` | 40037 | Relay 2 working mode | 16-bit unsigned | R/W |
| 37 | `0x0025` | 40038 | Relay 2 hysteresis | 16-bit unsigned | R/W |
| 38 | `0x0026` | 40039 | Relay 2 data type | 16-bit unsigned | R/W |
| 39 | `0x0027` | 40040 | Relay 2 action delay | 16-bit unsigned | R/W |
| 40 | `0x0028` | 40041 | Relay 2 upper limit low word  | 16-bit unsigned low  | R/W |
| 41 | `0x0029` | 40042 | Relay 2 upper limit high word | 16-bit unsigned high | R/W |
| 42 | `0x002A` | 40043 | Relay 2 lower limit low word  | 16-bit unsigned low  | R/W |
| 43 | `0x002B` | 40044 | Relay 2 lower limit high word | 16-bit unsigned high | R/W |

### 22.5 Relay 3 registers

|  Dec | Hex | PLC | Name | Type | Access |
| ---: | --- | ----: | --- | --- | --- |
| 44 | `0x002C` | 40045 | Relay 3 working mode | 16-bit unsigned | R/W |
| 45 | `0x002D` | 40046 | Relay 3 hysteresis | 16-bit unsigned | R/W |
| 46 | `0x002E` | 40047 | Relay 3 data type | 16-bit unsigned | R/W |
| 47 | `0x002F` | 40048 | Relay 3 action delay | 16-bit unsigned | R/W |
| 48 | `0x0030` | 40049 | Relay 3 upper limit low word  | 16-bit unsigned low  | R/W |
| 49 | `0x0031` | 40050 | Relay 3 upper limit high word | 16-bit unsigned high | R/W |
| 50 | `0x0032` | 40051 | Relay 3 lower limit low word  | 16-bit unsigned low  | R/W |
| 51 | `0x0033` | 40052 | Relay 3 lower limit high word | 16-bit unsigned high | R/W |

---

## 23. Validation and commissioning checklist

### Electrical
- [ ] Correct board version identified (AC vs DC)
- [ ] Sensor wired to `E+ E- S+ S-`
- [ ] No sensor / RS485 / AO line accidentally tied to mains
- [ ] Cabinet grounding handled externally

### Functional
- [ ] Unit powers on and exits `PoiNt`
- [ ] Zero works with no load
- [ ] Tare works with preload
- [ ] Span / calibration checked with known mass or force
- [ ] Overload behavior checked
- [ ] Peak capture behavior checked

### Outputs
- [ ] Relay thresholds tested
- [ ] AO scaling validated with meter / PLC card
- [ ] RS485 readback validated
- [ ] DI trigger behavior validated

---

## Recommended calibration configuration

The following table captures the recommended menu settings for the Handgrip calibration reference chain. The priority is reproducible calibration, not generic weighing-indicator operation.

### System settings (`C1.SyS`)

| Menu code | Label | Recommended value | Effect | Risk if wrong |
| --- | --- | --- | --- | --- |
| `100.SP`  | Internal sampling | `640 Hz` | Internal ADC acquisition rate | Too low loses timing detail |
| `101.GA`  | ADC gain | `128B` | Matches PM58 mV/V range to ADC resolution | Wrong gain can saturate or reduce resolution |
| `102.ME`  | Median filter | `3` | Suppresses impulse outliers | Too high adds lag |
| `103.rV`  | Average filter | `5` | Modest reference smoothing | Too high adds lag |
| `105.uN`  | Unit | `N` | Reference force in Newtons | Unit mismatch causes conversion errors in reports |
| `106.bi`  | Decimal point | `1` | Display granularity | Too fine makes stability windows unrealistic |
| `108.ro`  | Maximum range | `900.0 N` | Defines operating cap | Unsafe or saturated range if wrong |
| `109.di`  | DI input function | `NoNE` | Prevents accidental remote zero/tare | Stray input can silently zero during calibration  |

### Reference calibration (`C2.CAL`)

| Menu code | Label | Recommended value | Notes |
| --- | --- | --- | --- |
| `201.Mo`  | Calibration mode | `Load` | Use known-load calibration; datasheet mode is lower quality |
| `204.SE`  | Datasheet sensitivity | `1.504 mV/V` | PM58 certificate value; used for datasheet backup mode |
| `205.rE`  | Excitation | `5.000 V` | Board excitation reference |

### Advanced functions (`C4.AdV`) — disable hidden corrections

| Menu code | Label | Recommended value | Why |
| --- | --- | --- | --- |
| `400.CV`  | Creep tracking | `0` | Hides real drift during calibration |
| `401.dZ`  | Display zero mask | `0` | Hides real offset |
| `402.tV`  | Dynamic tracking | `0` | Can distort force trace |
| `404.SV`  | Stable weight switch | `0` | Hides evolving signal |
| `406.PZ`  | Power-on zero | `0` | Prevents silent baseline shift at startup |
| `409.AZ`  | Auto-zero | `0` | Prevents hidden drift correction during session |

### RS485 communication (`C5.CoM`)

| Menu code | Label | Recommended value | Notes |
| --- | --- | --- | --- |
| `500.Ar`  | Address | `1` | Must match `RS485_GUI` config |
| `501.br`  | Baud | `460800` | Required for Active-Send at 500 Hz |
| `502.Vb`  | Parity | `none` | Must match `RS485_GUI` config |
| `503.so`  | Stop bits | `1` | Must match `RS485_GUI` config |
| `504.AS`  | RS485 mode | `1` (Active-Send) | Recommended; `0` = Modbus RTU fallback |
| `505.AF`  | Active-Send rate | `500 Hz` | High enough to preserve timing detail  |

### Commissioning sequence

1. Configure `C1.SyS` system settings.
2. Configure `C2.CAL` reference calibration with a known traceable load.
3. Disable hidden corrections under `C4.AdV`.
4. Configure RS485 under `C5.CoM`.
5. Validate reference acquisition in `RS485_GUI` before calibration recording.
6. Backup settings only after validation.

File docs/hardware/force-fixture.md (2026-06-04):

# PM58 + Handgrip Force Application Fixture

## Summary

This document explains the mechanical force path used to calibrate the Handgrip target against the PM58 reference load cell and the acquisition board.

The fixture has three documentation stages:

1. **PM58 in series with handgrip** — proves the reference sensor and the target device are mechanically in the same force path.
2. **PM58 + handgrip connected to acquisition board** — proves the mechanical path is connected to the electrical reference chain.
3. **Screw press controlled-force setup** — proves the system can apply repeatable controlled force for static holds, calibration, and verification.

Use this document before executing Handgrip calibration. Use [docs/hardware/pm58-wiring-and-bringup.md](pm58-wiring-and-bringup.md) for electrical wiring and [docs/hardware/acquisition-board-reference.md](acquisition-board-reference.md) for acquisition-board menus.

## Safety and mechanical assumptions

### Known assumptions

- The PM58 is the **reference force sensor**.
- The handgrip target is the **device under calibration**.
- The useful calibration force is the force transmitted through the shared mechanical chain, not merely the force applied somewhere near the fixture.
- The screw press is used to make force application slower, more repeatable, and less operator-dependent than free-hand squeezing.

### Required mechanical safety rules

- Keep fingers clear of the screw press and moving contact surfaces.
- Do not exceed the safe force range of the handgrip target, PM58 load cell, fixture hardware, or acquisition board configuration.
- Increase force slowly during first validation; do not jump directly to high loads.
- Stop if the force path visibly bends, slips, rotates, tilts, or unloads one sensor relative to the other.
- Treat any slipping or non-repeatable contact as a failed fixture validation, not as a software/calibration issue.

### Calibration assumption that must be true

The PM58 and handgrip must experience the same axial force with minimal off-axis loading, backlash, compliance, or frictional bypass. If this is not true, the calibration fit may look numerically clean while being mechanically invalid.

## Fixture stages

The fixture photos are organized as an operator checklist. Use the visible hardware relationships first, then use the text checks below each stage.

### Stage 1 — PM58 in series with handgrip

| Primary view | PM58 identity cross-check |
| --- | --- |
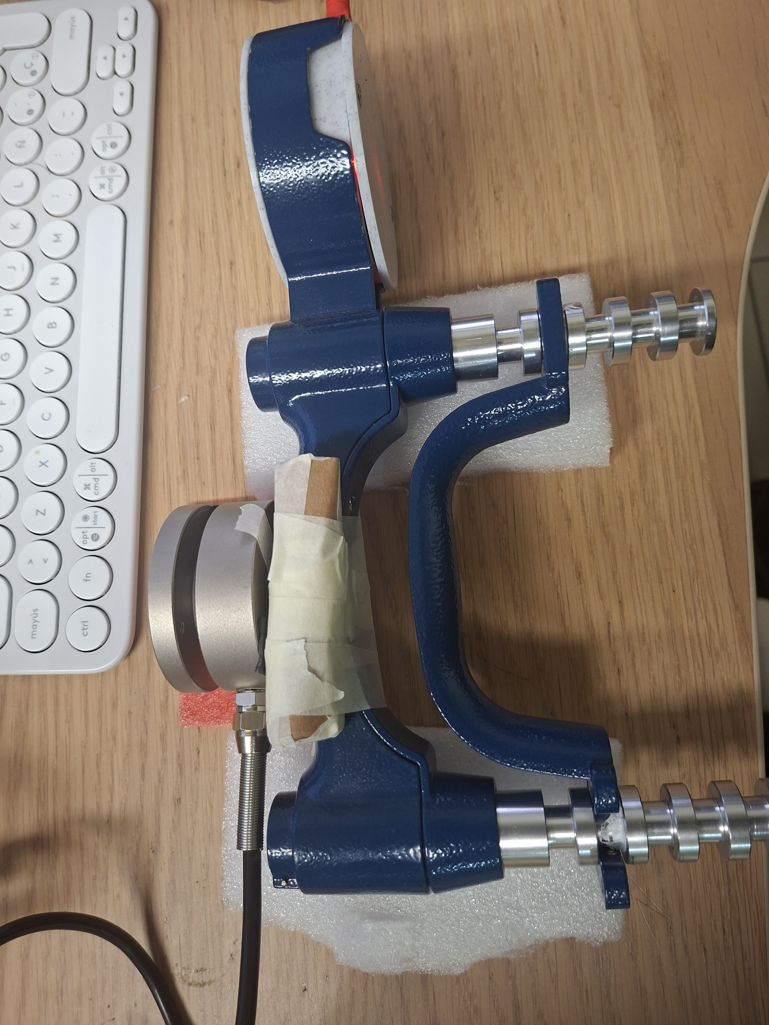
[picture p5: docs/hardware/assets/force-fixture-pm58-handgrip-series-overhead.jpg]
PM58 and handgrip mechanically arranged in series
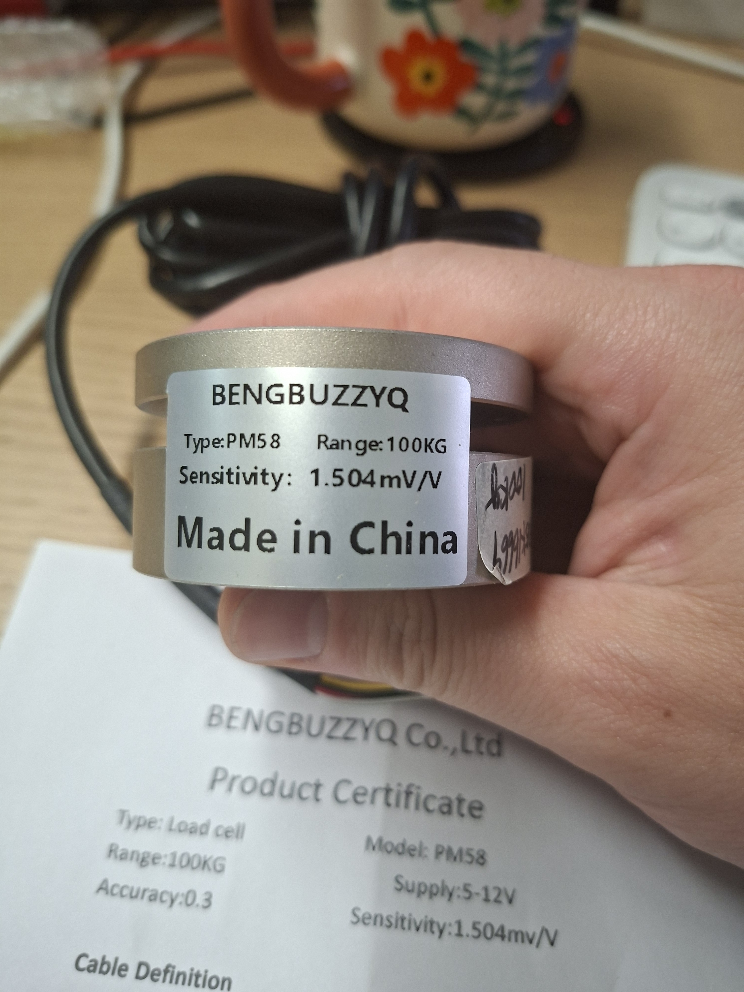
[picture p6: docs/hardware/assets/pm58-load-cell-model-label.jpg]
PM58 load-cell model label
| <br><sub>PM58 reference cell and handgrip target arranged in the same mechanical force path.</sub><br>[Open image](assets/force-fixture-pm58-handgrip-series-overhead.jpg) | <br><sub>PM58 model/range label used to confirm the reference sensor identity.</sub><br>[Open image](assets/pm58-load-cell-model-label.jpg) |

**Image files:**

- `docs/hardware/assets/force-fixture-pm58-handgrip-series-overhead.jpg`
- `docs/hardware/assets/pm58-load-cell-model-label.jpg`

**Purpose:** Show that the PM58 reference sensor and the handgrip target are mechanically arranged in series.

**What to verify from the image:**

- The applied force path passes through both the PM58 and the handgrip target.
- The sensors are not side-loaded or bypassed by another mechanical support.
- The contact surfaces are aligned enough that force is primarily axial.
- The handgrip target is not loose, tilted, or under asymmetric preload.

### Stage 2 — PM58 + handgrip connected to acquisition board

| Fixture + board overview | Rear terminal cross-check |
| --- | --- |
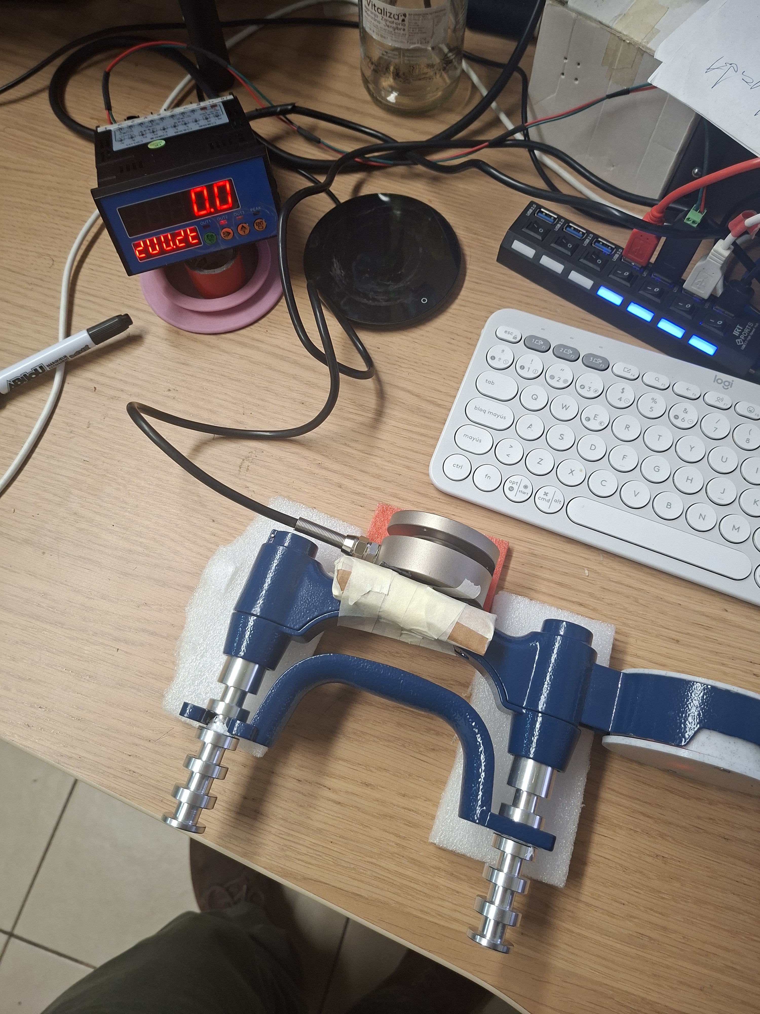
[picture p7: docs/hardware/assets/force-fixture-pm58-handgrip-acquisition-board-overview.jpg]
PM58 and handgrip fixture connected to the acquisition board
| <br><sub>Mechanical series chain with the PM58 reference path electrically connected to the acquisition board.</sub><br>[Open image](assets/force-fixture-pm58-handgrip-acquisition-board-overview.jpg) | Rear terminal map of the full-feature acquisition board<br><sub>Use terminals `5-8` for PM58 sensor wiring and terminals `19/20` for AC power on this board variant.</sub><br>[Open image](assets/acquisition-board-rear-terminal-map-full-feature.jpg) |

**Image files:**

- `docs/hardware/assets/force-fixture-pm58-handgrip-acquisition-board-overview.jpg`
- `docs/hardware/assets/acquisition-board-rear-terminal-map-full-feature.jpg`

**Purpose:** Show the same mechanical series chain with the PM58 electrically connected to the acquisition board.

**What to verify from the image:**

- PM58 wires route to the acquisition board sensor terminal block.
- Sensor wiring does not cross or strain the moving force path.
- AC power and sensor wiring are physically separated as much as practical.
- RS485 wiring has enough slack and does not mechanically pull the board or sensor.

### Stage 3 — Screw press controlled-force setup

| Controlled-force contact | Full bench context |
| --- | --- |
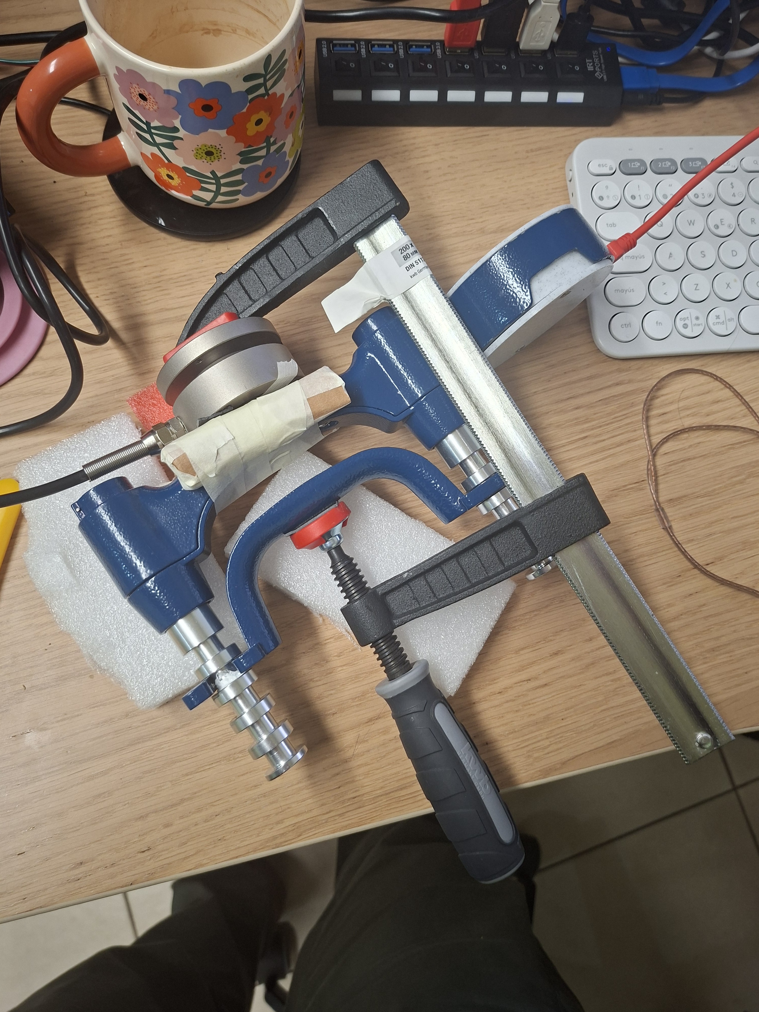
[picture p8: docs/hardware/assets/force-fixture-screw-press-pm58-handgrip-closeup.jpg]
Screw press applying controlled force through PM58 and handgrip
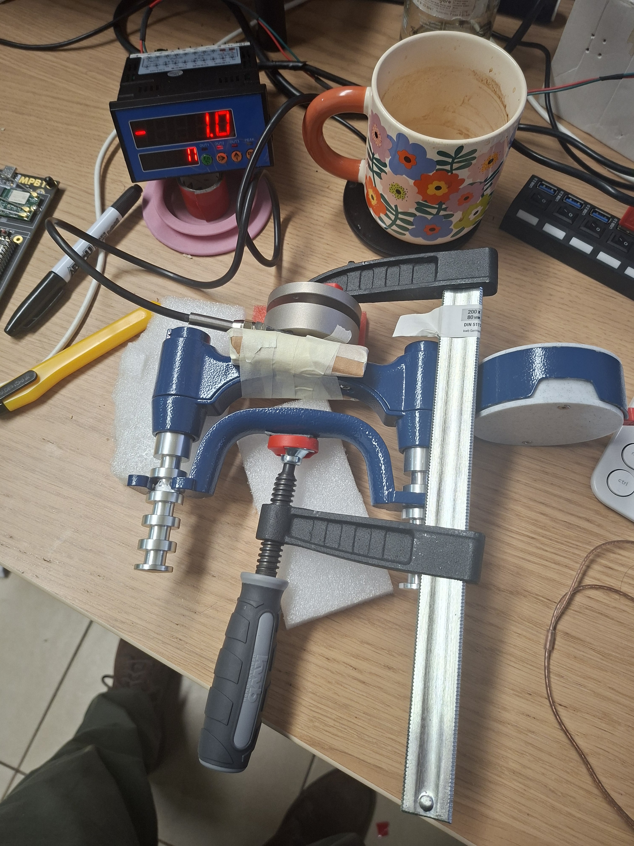
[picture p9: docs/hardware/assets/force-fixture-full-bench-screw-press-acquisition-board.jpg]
Full bench view with screw press, PM58, handgrip, and acquisition board
| <br><sub>Screw press contact point and local alignment against the PM58 + handgrip chain.</sub><br>[Open image](assets/force-fixture-screw-press-pm58-handgrip-closeup.jpg) | <br><sub>Complete bench layout used to inspect cable routing, operator access, and acquisition-board placement.</sub><br>[Open image](assets/force-fixture-full-bench-screw-press-acquisition-board.jpg) |

**Image files:**

- `docs/hardware/assets/force-fixture-screw-press-pm58-handgrip-closeup.jpg`
- `docs/hardware/assets/force-fixture-full-bench-screw-press-acquisition-board.jpg`

**Purpose:** Show the controlled-force fixture used to apply repeatable loads through the PM58 + handgrip chain.

**What to verify from the image:**

- The screw press applies force along the same axis as the PM58 + handgrip chain.
- The contact point is stable and does not slide during loading.
- The fixture base is rigid enough that applied displacement mostly becomes sensor force, not frame deformation.
- There is enough clearance to operate the setup without touching live wiring or moving contact points.
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

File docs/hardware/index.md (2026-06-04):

# Hardware Documentation

## Summary

This folder contains canonical hardware setup, reference, and fixture documentation.

## Visual navigation

| Area | Open this first | Visual reference |
| --- | --- | --- |
| PM58 wiring and acquisition-board bring-up | [docs/hardware/pm58-wiring-and-bringup.md](pm58-wiring-and-bringup.md) | Rear terminal map of the acquisition board<br><sub>Use this to locate `1=A+`, `2=B-`, `5=E+`, `6=E-`, `7=S-`, `8=S+`, `19=L`, `20=N`.</sub> |
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

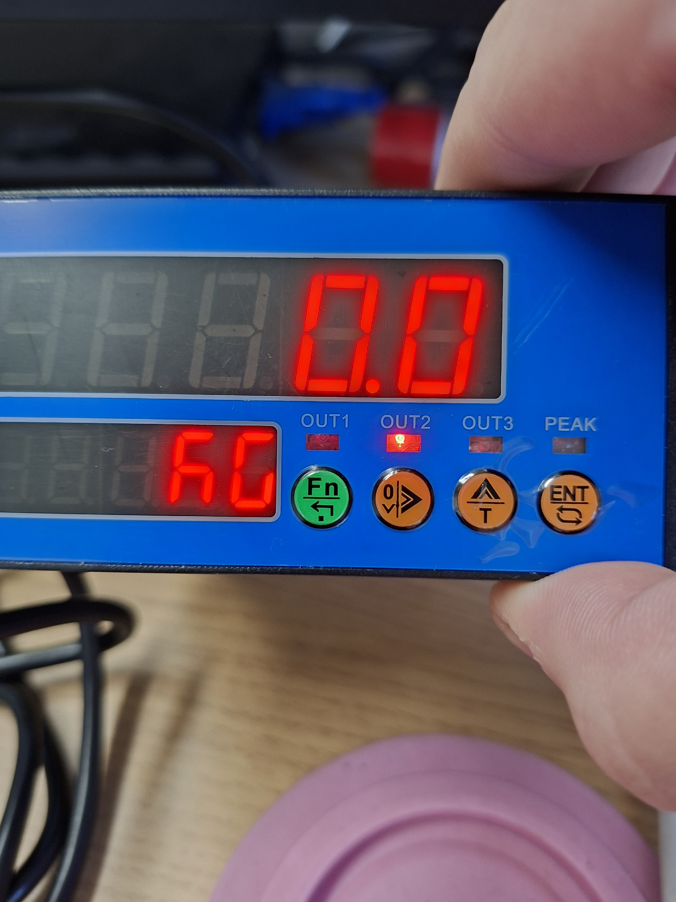
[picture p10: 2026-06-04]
docs/hardware/assets/acquisition-board-front-panel-startup-force-reading.jpg

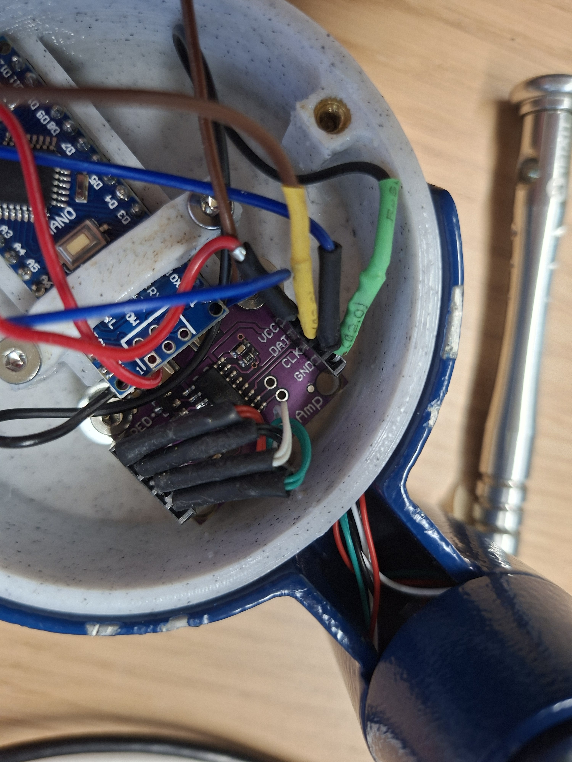
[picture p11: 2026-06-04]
docs/hardware/assets/adc_module_to_arduino.jpg

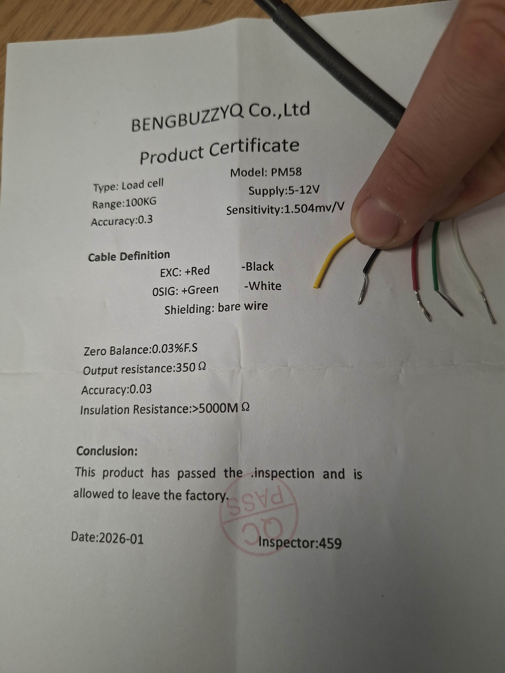
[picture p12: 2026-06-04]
docs/hardware/assets/pm58-certificate_wire-colors.jpg

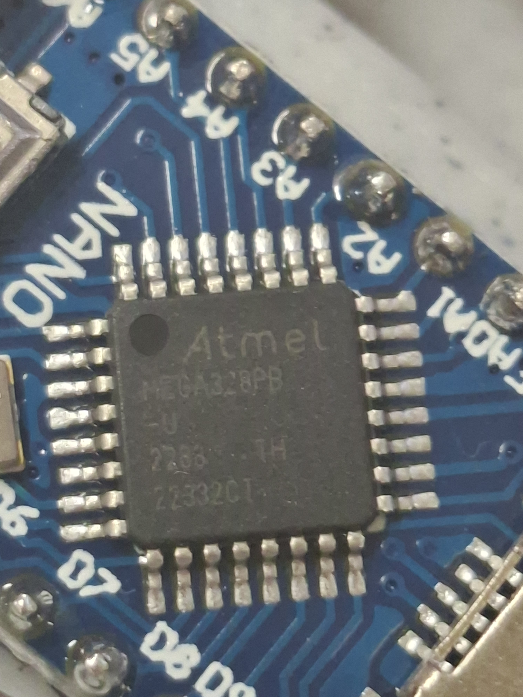
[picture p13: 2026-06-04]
docs/hardware/assets/mcu_2.jpg

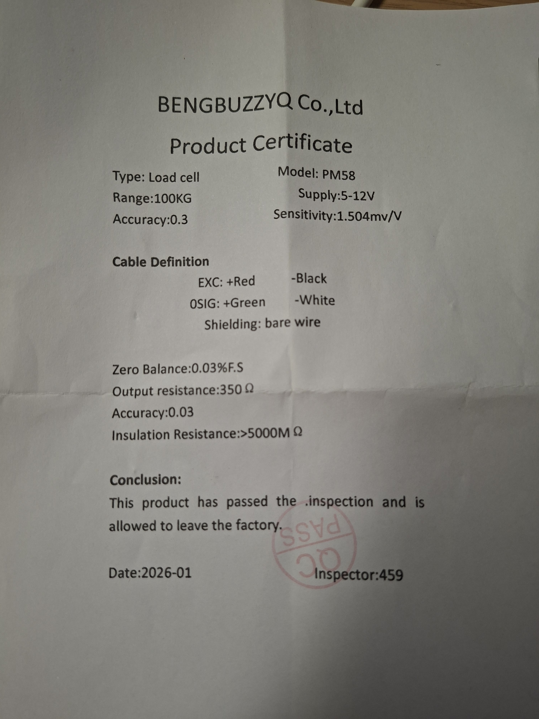
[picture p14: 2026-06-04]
docs/hardware/assets/pm58-certificate.jpg

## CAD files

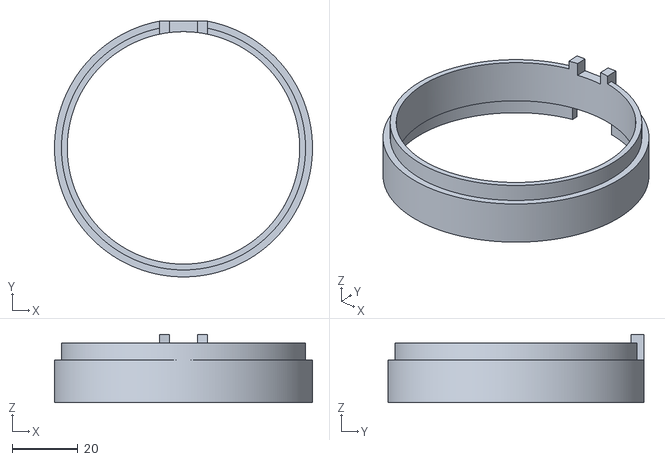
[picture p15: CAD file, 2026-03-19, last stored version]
Piezas/Ring.stl
78.5 x 77.8 x 20.7

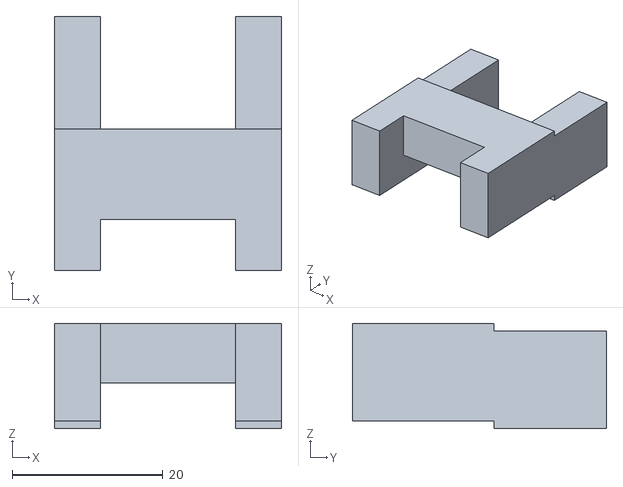
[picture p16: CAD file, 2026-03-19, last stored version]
Piezas/Soportev2.stl
30.2 x 33.8 x 14.0

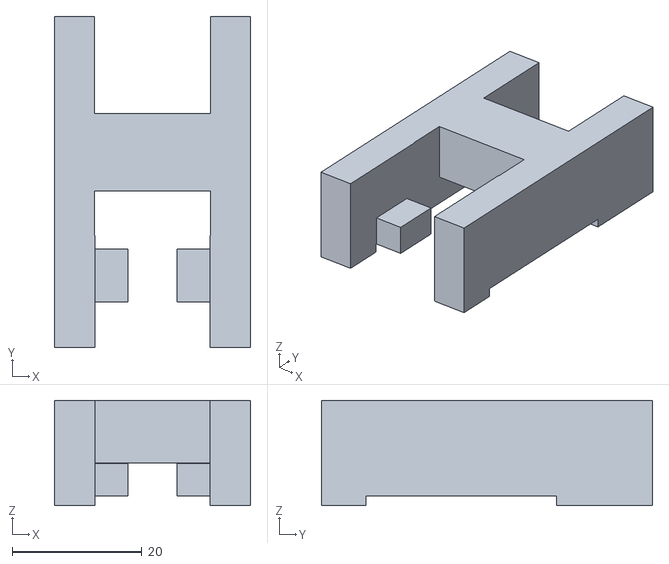
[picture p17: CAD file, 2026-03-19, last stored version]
Piezas/V3/Soporte.stl
30.2 x 51.1 x 16.2

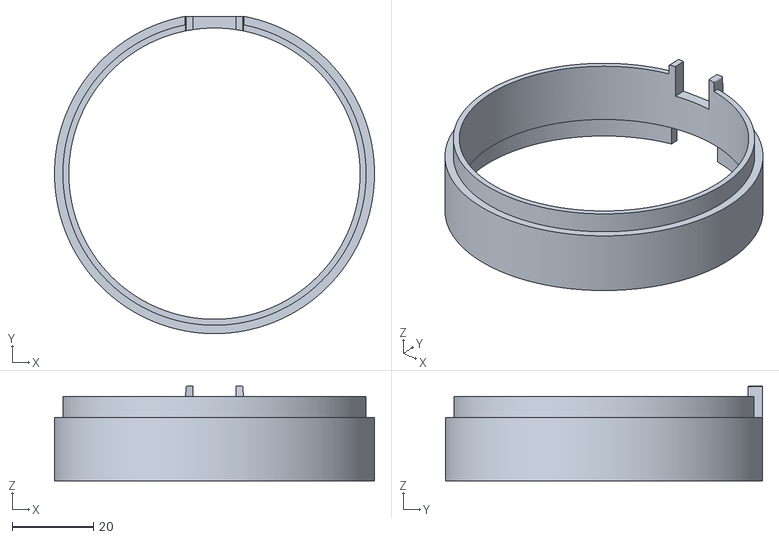
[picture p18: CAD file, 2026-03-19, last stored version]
Piezas/V3/Ring.stl
78.9 x 78.2 x 23.4

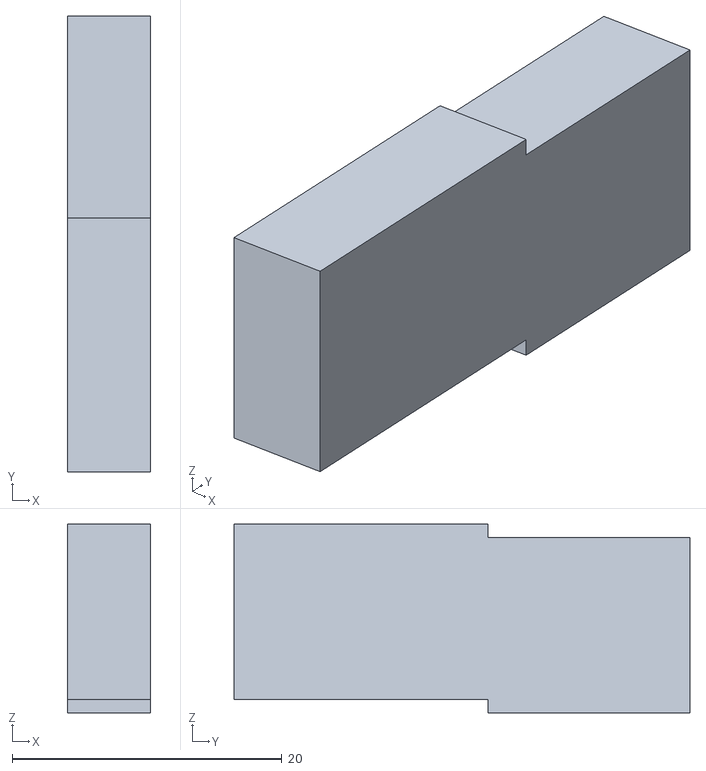
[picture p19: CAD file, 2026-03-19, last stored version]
Piezas/Soporte.stl
6.14 x 33.8 x 14.0

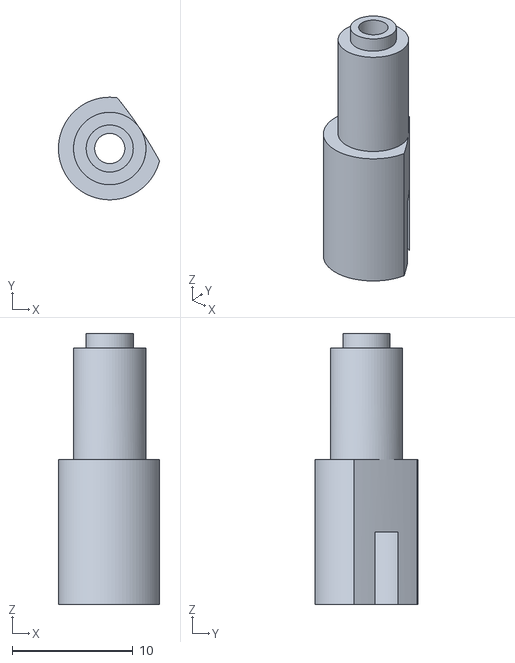
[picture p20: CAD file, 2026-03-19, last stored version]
Piezas/V3/Screw.stl
8.38 x 8.50 x 22.4

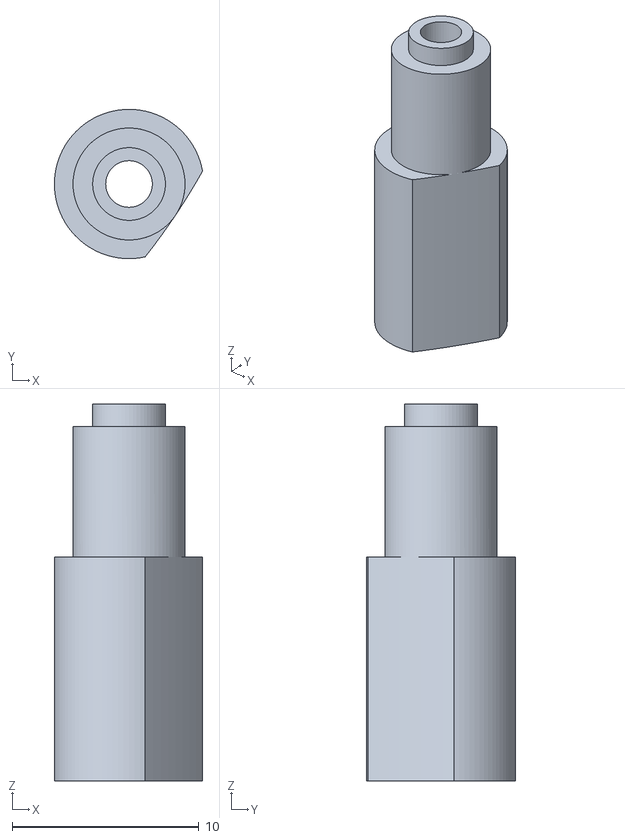
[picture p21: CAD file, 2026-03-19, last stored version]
Piezas/Screw.stl
7.94 x 8.00 x 20.2

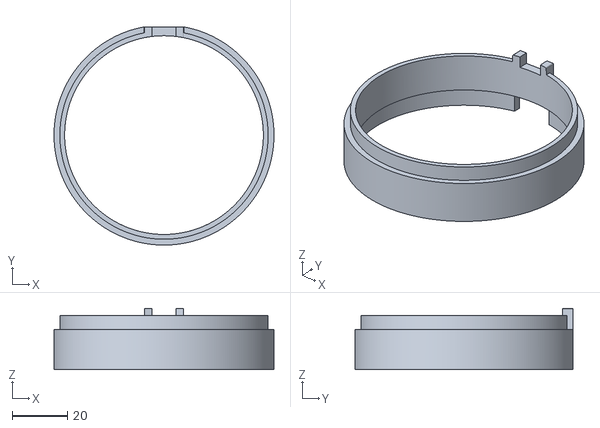
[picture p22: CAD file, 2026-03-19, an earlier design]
Piezas/V2/Ring.stl
79.5 x 78.8 x 22.2

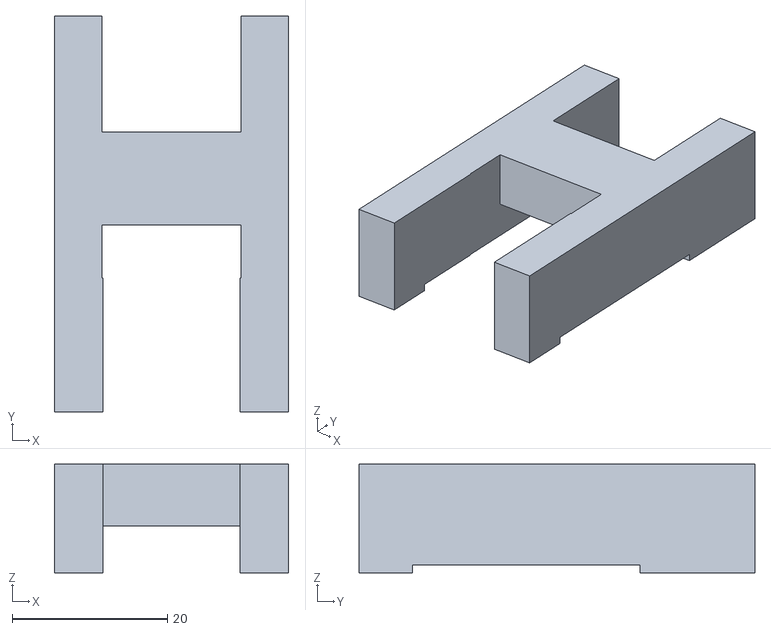
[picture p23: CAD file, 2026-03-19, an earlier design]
Piezas/V2/Soporte.stl
30.2 x 51.1 x 14.0

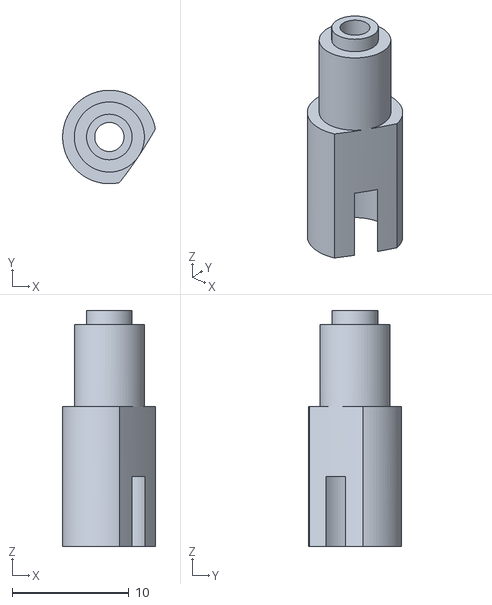
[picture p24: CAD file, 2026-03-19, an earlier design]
Piezas/V2/Screw.stl
7.94 x 8.00 x 20.2

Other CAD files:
Piezas/AC3E v0.f3d

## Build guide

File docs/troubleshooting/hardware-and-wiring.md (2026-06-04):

# Hardware and Wiring Troubleshooting

## Summary
**Symptoms covered:** No board display, wrong load sign, unstable reading, overload

**Start here** — no upstream prerequisite. Resolve physical system issues in this guide before moving to [docs/troubleshooting/serial-and-rs485.md](serial-and-rs485.md).

Start here when the physical system does not behave correctly before software acquisition. Do not debug Python until the board display and force path make physical sense.

## Symptom: no board display

### Likely causes

| Cause | Check | Fix |
| --- | --- | --- |
| No power | AC input disconnected or switched off | Verify power source and disconnect/reconnect safely. |
| Wrong board power variant | Board not actually AC-powered | Confirm label before applying power. |
| Loose L/N wiring | Terminal not clamped | Power down, re-seat wiring. |
| Board fault | No display despite verified power | Stop and replace/inspect board. |

### Stop condition

Stop immediately if there is heat, smell, flicker, exposed mains wiring, or uncertain board power rating.

## Symptom: wrong load sign

### Likely causes

| Cause | Check | Fix |
| --- | --- | --- |
| Signal pair reversed | PM58 `S+`/`S-` swapped | Swap signal pair after powering down. |
| Mechanical direction reversed | Compression/tension convention differs  | Document sign convention; only invert if consistent and intended. |
| Board display scaling/inversion setting | Board menu sign/scaling setting changed | Compare against acquisition-board menu reference. |

### Validation

Apply a small known force. The reference and target should move in the expected direction for the calibration workflow.

## Symptom: unstable reading

### Likely causes

| Cause | Check | Fix |
| --- | --- | --- |
| Loose sensor wire | Reading changes when cable moves | Power down and re-seat terminals. |
| Shield/drain misused | Noise changes with cable position | Keep shield isolated initially unless grounding plan is validated. |
| Mechanical slip | Reading jumps during hold | Rebuild fixture, add clamping/stops. |
| Hidden board filtering/tracking | Display value behaves non-physically | Review acquisition-board menu reference. |
| Electrical noise | Noise correlated with mains/USB movement | Separate sensor wiring from power wiring. |

## Symptom: overload / saturated reading

### Likely causes

| Cause | Check | Fix |
| --- | --- | --- |
| Sensor overloaded | Force exceeds PM58 range | Release load immediately. |
| Wrong gain/range setting | Board saturates under small force | Restore recommended calibration configuration. |
| Wiring fault | Saturated with no load | Re-check E+/E-/S+/S- wiring. |
| Mechanical preload | Fixture starts loaded | Release screw press, zero only after stable no-load state. |

## Minimum physical validation before software

- [ ] Acquisition board powers on normally.
- [ ] PM58 display responds to small force.
- [ ] Force path is stable and does not slip.
- [ ] Target handgrip wiring is secure.
- [ ] No overload or unstable baseline is present.
- [ ] Screw press force path is visually aligned.

**Related docs:** [docs/workflows/physical-setup.md](../workflows/physical-setup.md), [docs/hardware/pm58-wiring-and-bringup.md](../hardware/pm58-wiring-and-bringup.md), [docs/hardware/force-fixture.md](../hardware/force-fixture.md)

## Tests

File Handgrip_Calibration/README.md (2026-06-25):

# Handgrip Calibration

## Summary

`Handgrip_Calibration` records calibration sessions, segments protocol events, fits target-to-reference force models, generates reports, and validates accepted models with holdout recordings.

The canonical primary calibration protocol is:

```text
conf/protocol_static_reversible_staircase_v3.yaml
```

## First command

From the repo root or from `Handgrip_Calibration/`, after the live stack is
running — `conf/...yaml` and `data/calibration/<session_id>` resolve the same
in both locations, and recorded sessions always land under
`Handgrip_Calibration/data/calibration/`:

```bash
uv run handgrip-cal preflight --config conf/protocol_static_reversible_staircase_v3.yaml
```

Record the primary protocol:

```bash
uv run handgrip-cal record --config conf/protocol_static_reversible_staircase_v3.yaml
```

## Expected result

Expected successful behavior:

- preflight discovers `HandgripTarget` and `HandgripReference`,
- required channels exist,
- protocol config validates,
- recording creates `data/calibration/<session_id>/`,
- session folder contains target/reference samples, events, quality logs, and config snapshots,
- fitting generates selected model artifacts,
- reporting generates human-readable calibration reports.

Stop if preflight cannot find both streams or if the physical force path has not been validated.

## Configuration

Primary config/protocol files:

| File | Purpose |
| --- | --- |
| `conf/protocol_static_reversible_staircase_v3.yaml` | Canonical primary calibration protocol. |
| `conf/protocol_reference_verification.yaml` | Reference-chain verification before main calibration. |
| `conf/protocol_holdout_verification.yaml` | Independent post-fit validation. |
| `conf/protocol_smoke_test_capture.yaml` | Fast pipeline smoke test — primary capture (0, 20, 40 N, 2 s holds). |
| `conf/protocol_smoke_test_holdout.yaml` | Fast pipeline smoke test — holdout validation capture (0, 15, 30 N). |
| `conf/default.yaml` / `conf/config.yaml` | Base/default calibration settings, depending on command path. |
| `conf/template.yaml` | Starting point for new protocol definitions. |

Full configuration reference is planned at [Handgrip_Calibration/docs/configuration.md](docs/configuration.md).

## Documentation

Full reading guide, per-document map, and related cross-component docs: [Handgrip_Calibration/docs/index.md](docs/index.md).

## Repository layout

```text
Handgrip_Calibration/
├── README.md
├── conf/
│   ├── protocol_static_reversible_staircase_v3.yaml
│   ├── protocol_reference_verification.yaml
│   ├── protocol_holdout_verification.yaml
│   └── ...
├── docs/
│   ├── index.md
│   └── protocols.md
├── src/
│   └── handgrip_calibration/
│       ├── cli.py
│       ├── recorder.py
│       ├── fitting.py
│       ├── validation.py
│       ├── protocol_analysis.py
│       └── report.py
├── data/
│   └── calibration/
└── tests/
```

## Tests

Run from `Handgrip_Calibration/` after dependencies are installed:

```bash
uv run pytest
```

Fast hardware-free validation pattern:

```bash
uv run handgrip-cal demo-data --output /tmp/hg_demo
uv run handgrip-cal fit /tmp/hg_demo/demo_handgrip_session --config conf/default.yaml
uv run handgrip-cal report /tmp/hg_demo/demo_handgrip_session
```

Smoke test — full end-to-end pipeline with live hardware (not for production):

```bash
uv run handgrip-cal record \
  --config conf/protocol_smoke_test_capture.yaml --session-id smoke_capture_01
uv run handgrip-cal fit \
  data/calibration/smoke_capture_01 --config conf/protocol_smoke_test_capture.yaml
uv run handgrip-cal report data/calibration/smoke_capture_01
uv run handgrip-cal record \
  --config conf/protocol_smoke_test_holdout.yaml --session-id smoke_holdout_01
uv run handgrip-cal validate-holdout \
  data/calibration/smoke_holdout_01 \
  --model data/calibration/smoke_capture_01/fit_result.json \
  --config conf/protocol_smoke_test_holdout.yaml
# Expected: calibration_report.md in smoke_capture_01/ regenerated with integrated holdout section
```

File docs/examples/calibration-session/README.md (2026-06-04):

# Curated Calibration Session Example

## Summary

Small, curated excerpts showing how to interpret calibration outputs. Raw session data belongs in `Handgrip_Calibration/data/calibration/<session_id>/`.

## What a complete calibration session usually contains

| Artifact | Purpose | How to interpret |
| --- | --- | --- |
| `target.csv` | Captured `HandgripTarget` samples. | Confirms raw target counts, timestamps, and status values. |
| `reference.csv` | Captured `HandgripReference` samples. | Confirms PM58/reference force values. |
| `events.ndjson` | Protocol/marker events. | Segment baseline, preload, static holds, dynamic trials, and holdout events. |
| `quality_live.ndjson` | Live QA telemetry. | Check sample rates, gaps, unstable holds, and runtime warnings. |
| `session_manifest.yaml` | Session metadata. | Identify operator, purpose, protocol, output root, and provenance. |
| `component_configs/` | Copied configs from bridge/viewer/RS485/calibration. | Reproduce the acquisition context. |
| `calibration_dataset.csv` | Segmented/accepted fit dataset. | Confirm accepted holds and force levels used for fitting. |
| `fit_candidates.json` | All evaluated model candidates. | Compare models and complexity. |
| `fit_result.json` | Selected model and deployment values. | Source of accepted model parameters. |
| `model_selection_report.json` | Machine-readable model-selection evidence. | Audit metric/likelihood/residual choices. |
| `calibration_report.md` / `.html` | Human-readable report. | Primary review artifact for handoff. |
| `plots/` | Diagnostic plots. | Residuals, selected fit curve, hysteresis, weights, likelihoods. |

## Selected interpretation path

1. Open `calibration_report.md`.
2. Confirm the report identifies the session ID and protocol.
3. Check whether the primary model is selected from accepted candidates.
4. Inspect residual plots by force level.
5. Inspect up/down hysteresis if available.
6. Confirm firmware constants or deployment instructions are explicitly reported.
7. Run or inspect holdout validation before treating the model as accepted.

## Good report signs

- Session ID and protocol are explicit.
- The report states target signal and reference signal names.
- `reference_force_N = f(target_raw_count)` remains the core calibration relation.
- Residuals are not systematically biased by force level.
- The selected model is not more complex than necessary.
- Config snapshots exist and include the real RS485 GUI config path: `../RS485_GUI/config/config.yaml`.

## Anti-example signs

- Missing `target.csv` or `reference.csv`.
- Missing `events.ndjson` or protocol markers.
- Model selected without residual/holdout evidence.
- Report describes fitting against firmware-scaled `current_units` without explicitly saying this is an already-deployed-constant validation.
- Component configs are missing or copied from stale paths.

## Curation rule

Only place small explanatory excerpts here, for example:

```text
docs/examples/calibration-session/
├── README.md
├── selected-report-excerpts.md
└── selected-plot-notes.md
```

## Related docs:

- [docs/workflows/handgrip-calibration.md](../../workflows/handgrip-calibration.md)
- [Handgrip_Calibration/docs/reports-and-outputs.md](../../../Handgrip_Calibration/docs/reports-and-outputs.md)

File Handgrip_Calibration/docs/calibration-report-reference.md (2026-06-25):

# Calibration Report Reference

## 1. How to read this reference

This document explains the static concepts used by the Handgrip calibration report. It is written for reviewers who need to understand what each number, model, plot, and table means before deciding whether a calibration is safe to use.

A calibration report is not only a curve fit. It is a chain of evidence:

1. The target and reference streams were captured cleanly.
2. Static holds were segmented and accepted by quality gates.
3. Candidate models were fitted to accepted holds.
4. The selected model was checked against residual thresholds and cross-validation.
5. If available, an independent holdout session was used as a final deployment gate.
6. Firmware constants were exported only after the fit and holdout checks were acceptable.

The report follows the standard calibration idea of relating a sensor response to known or reference loads, then using that fitted relationship to estimate future loads. NIST describes load-cell calibration this way: a model relates a known load to a cell response and is then used for readings of unknown magnitude [\[R02\]](#R02). NIST force-calibration service material also notes that calibration commonly derives polynomial equations from force/response data [\[R18\]](#R18).

## 2. Quick decision reading order

Read the report in this order when making a deployment decision:

1. **Firmware deployment recommendation**: If this says `do_not_deploy...`, stop and investigate.
2. **Holdout accuracy summary**: Prefer decisions based on independent holdout data. A good fit on the same holds used for training is not enough.
3. **Residual threshold pass**: Confirms the selected fit did not exceed the configured worst-error gate.
4. **Model candidate ranking**: Check whether a more complex model only marginally improves the score.
5. **Residual plots**: Look for curvature, load-dependent bias, outliers, or direction-specific effects. NIST emphasizes graphical residual analysis because residual plots reveal patterns that a single number may hide [\[R01\]](#R01).
6. **Reference-chain verification summary**: Confirm the data capture itself was healthy before trusting the model.
7. **Hysteresis / creep / dynamic sections**: Treat these as diagnostic layers. They should influence whether to trust the calibration, not silently change the primary static fit.

## 3. Core calibration vocabulary

### 3.1 Target stream

The **target stream** is the handgrip sensor being calibrated. In the current report it is usually represented as raw counts or target units. The fitting stage treats its median value during a stable hold as the independent input variable: `target_raw_median`.

Interpretation: if the target raw value is noisy, discontinuous, or direction-dependent, the calibration may be unstable even if a fitted line looks good.

### 3.2 Reference stream

The **reference stream** is the force/reference device used as the temporary ground truth. In this project it is the RS485 reference chain. The fitting stage usually uses `reference_force_median_N` as the output variable in Newtons.

Interpretation: the reference stream must be cleaner and more trustworthy than the target stream. The report therefore starts with stream health and reference-chain verification before model quality.

### 3.3 Static hold

A **static hold** is a protocol interval where the operator holds a nominal force level long enough for the target and reference readings to stabilize. Static staircase holds are the primary fitting material. Dynamic trials are validation/diagnostic material, not primary coefficient estimators.

### 3.4 Residual

A **residual** is the observed response minus the model prediction for the same point. In the calibration report:

```text
residual_N = reference_force_median_N - predicted_force_N
```

Positive residual means the model predicted too low. Negative residual means the model predicted too high. NIST defines residuals as the difference between observed responses and corresponding fitted-model predictions [\[R01\]](#R01).

### 3.5 Operating range

The **operating range** is the configured force range over which the calibration is expected to be used. Percent-range errors divide Newton error by this configured range. This is useful because a 1 N error has different meaning on a 20 N instrument versus a 100 N instrument.

## 4. Report sections

### 4.1 Summary

The summary gives the minimum deployment context:

- `Session ID`: the session directory name.
- `Operator`: operator from the session manifest if available.
- `Purpose`: why the session was recorded.
- `Protocol`: protocol name and type.
- `Selected model`: model selected by the model-selection policy.
- `Model-selection likelihood`: normalized relative decision weight among eligible candidates.
- `Affine-compatible equation`: `force_N = a * raw + b` when available.
- `RMSE`: root-mean-square error on accepted calibration holds.
- `Max abs error`: worst accepted-hold residual magnitude.
- `Residual threshold pass`: selected-model gate result.
- `Firmware deployment recommendation`: final report-level deployment call.

Interpretation: this section is a dashboard. Do not use it alone to approve a calibration.

### 4.2 Reference-chain verification summary

This section checks whether target/reference acquisition looked healthy before fitting. It includes:

| Field | Meaning | How to interpret |
| --- | --- | --- |
| `stream` | Target or reference stream. | Both should be present for a valid calibration. |
| `n_samples` | Number of samples captured. | Very low counts imply missing data or short capture. |
| `duration_s` | Stream duration in seconds. | Target/reference durations should roughly cover the same experiment. |
| `sample_rate_hz` | Approximate sample rate. | Compare to expected target/reference rates. Large deviations imply capture issues. |
| `max_gap_s` | Largest timestamp gap. | Large gaps indicate dropped data, blocking, or stream interruption. |
| `value_col` | Data column used for statistics. | Confirms the report selected the intended signal. |
| `mean`, `std`, `min`, `max` | Basic value statistics. | Useful for detecting saturation, out-of-range values, or unexpected units. |

Line plots are appropriate here because they show values against elapsed time [\[R14\]](#R14).

### 4.3 Event counts and event summary

The report counts each marker event and later lists event rows. These tables check whether the protocol structure was captured correctly.

Important events include `session_start`, `series_start`, `hold_start`, `stable_window_start`, `trial_accept`, `hold_end`, `calibration_candidate_selected`, `firmware_constants_exported`, and `session_end`.

Interpretation: missing or mismatched event counts usually mean the report should be treated as incomplete, even if the numeric fit succeeds.

### 4.4 Static fit summary

The static fit summary aggregates quality information over accepted holds:

| Field | Meaning | Interpretation |
| --- | --- | --- |
| `accepted_holds` | Holds accepted by operator/segmentation. | More force levels and repeats generally make model selection more reliable. |
| `quality_pass_holds` | Holds passing automatic quality checks. | If lower than accepted holds, inspect rejection reasons. |
| `reference_force_std_N_median/max` | Reference noise during holds. | Lower is better. High values mean unstable reference force. |
| `reference_slope_N_s_median/max` | Reference drift trend during holds. | Near zero is better for static calibration. |
| `reference_sample_rate_hz_*` | Reference stream sampling health during holds. | Should match expected reference acquisition rate. |
| `target_sample_rate_hz_*` | Target stream sampling health during holds. | Should match expected target acquisition rate. |
| `target_seq_gap_count_*` | Dropped-sample / sequence gap count. | Nonzero values indicate target stream discontinuity. |

### 4.5 Accepted hold dataset

Each row represents one static hold used or considered for fitting.

| Field | Meaning | Interpretation |
| --- | --- | --- |
| `trial_id` | Unique hold identifier. | Use it to trace outliers back to protocol events. |
| `target_force_nominal_N` | Nominal force requested by protocol. | Protocol target, not necessarily the measured reference force. |
| `direction` | Loading path: `ascending`, `descending`, or `flat`. | Used for hysteresis/reversibility checks. |
| `target_raw_median` | Median target raw value during stable window. | Main x-value used for fitting. |
| `reference_force_median_N` | Median reference force during stable window. | Main y-value used for fitting. |
| `reference_force_std_N` | Reference variability during the hold. | Used as noise evidence and weighting input. |
| `reference_slope_N_s` | Reference drift over the hold. | Large magnitude means the force was still changing. |
| `accepted_by_quality` | Automatic quality gate result. | False rows should not be trusted for primary fitting. |
| `quality_rejection_reason` | Gate failure reason. | Use it to fix protocol or acquisition issues. |

Medians and robust scale estimates are used because they are less sensitive to short spikes than simple means; SciPy describes median absolute deviation as a robust dispersion measure [\[R12\]](#R12).

### 4.6 Holdout accuracy summary

Holdout validation applies the selected model to an independent session. It does not refit the model. This is the strongest deployment evidence in the report because it estimates performance on data not used for fitting. Cross-validation uses train/test splits for the same general reason: estimate performance on unseen data [\[R11\]](#R11).

Holdout fields:

| Field | Meaning | Interpretation |
| --- | --- | --- |
| `n_points` | Number of accepted holdout points. | Too few points make the holdout gate weak. |
| `rmse_N` | Holdout RMSE. | Typical error magnitude on independent holds. |
| `mae_N` | Holdout MAE. | Average absolute error; easier to explain than RMSE. |
| `max_abs_error_N` | Worst holdout error. | Important for safety/release gate. |
| `max_abs_error_percent_range` | Worst holdout error as percent of range. | Normalized severity. |
| `bias_N` | Mean signed holdout residual. | Nonzero bias indicates systematic offset. |
| `residual_std_N` | Residual spread after bias. | Shows consistency independent of mean offset. |
| `r2` | Holdout coefficient of determination. | Useful but should not override residual errors. |
| `thresholds.*` | Configured release limits. | Deployment gate values. |
| `passes_holdout_gate` | Boolean holdout verdict. | If false, do not deploy without investigation. |
| `firmware_deployment_recommendation` | Final holdout-based recommendation. | Should agree with report-level recommendation. |

### 4.7 Hysteresis / reversibility summary

Hysteresis means the sensor can report a different raw value at the same force depending on whether force is increasing or decreasing. The report computes descending-minus-ascending differences at force levels where both directions exist.

| Field | Meaning | Interpretation |
| --- | --- | --- |
| `force_N` | Nominal force level compared. | Only levels with both directions appear. |
| `n_ascending`, `n_descending` | Number of holds per direction. | One per direction is a weak estimate; repeated cycles are better. |
| `target_raw_delta_desc_minus_asc` | Difference in target raw median. | Large values indicate load-path dependence in the target sensor/fixture. |
| `reference_force_delta_desc_minus_asc_N` | Reference force difference by direction. | Helps separate target hysteresis from reference/operator force mismatch. |

ISO 376 preview material explicitly distinguishes increasing and decreasing force series and includes reversibility error as a force-proving instrument characteristic [\[R17\]](#R17).

### 4.8 Creep / zero-return summary

Creep is slow output change while load is held. Zero-return checks whether the instrument returns close to its unloaded baseline after load removal. ISO 376 preview material includes a creep test and describes readings after force application or removal; it also notes zero changes after unloading as a diagnostic sign [\[R17\]](#R17).

| Field | Meaning | Interpretation |
| --- | --- | --- |
| `phase` | `creep` or `zero_return`. | Which diagnostic window was summarized. |
| `target_force_N` | Target force for the diagnostic phase. | The load level being tested. |
| `duration_s` | Phase duration. | Longer windows reveal slow effects. |
| `n_reference_samples` | Reference samples in the phase. | Low counts weaken the estimate. |
| `reference_start_mean_N`  | Mean force near phase start. | Baseline for change. |
| `reference_end_mean_N` | Mean force near phase end. | End state. |
| `delta_end_minus_start_N` | End minus start. | Slow drift or return error. |
| `slope_N_per_s` | Linear trend over the phase. | Direction and magnitude of slow change. |

### 4.9 Dynamic validation summary

Dynamic trials are ramps or squeezes. The current report records metadata such as `peak_force_N` and `speed_N_per_s`, but does not use them to fit primary static coefficients.

Interpretation: dynamic data is useful for lag, transient behavior, and real-use validation. Do not tune static calibration coefficients to dynamic artifacts before static performance is stable.

### 4.10 Firmware deployment recommendation

The report approves firmware constants only when the selected model passes residual gates and, when available, the independent holdout passes its gate.

Interpretation: `approve_constants_for_deployment` means the current evidence supports deployment. It does not mean the calibration is valid outside the calibrated raw-count and force range.

## 5. Plots

### 5.1 `target_timeseries`

A line plot of target raw counts/units against elapsed time. Line plots display y-values against x-values and are appropriate for visualizing streams over time [\[R14\]](#R14).

Look for:

- missing intervals or sudden timestamp gaps,
- hard clipping or saturation,
- unexpected jumps unrelated to protocol events,
- drift while force should be stable.

### 5.2 `reference_timeseries`

A line plot of reference raw/force against elapsed time.

Look for:

- whether force steps align with the protocol,
- whether stable windows are actually stable,
- whether the reference device has backlog, sudden jumps, or visible drift.

### 5.3 `model_comparison_curve`

A scatter plot of accepted holds plus candidate calibration curves. Scatter plots place paired x/y observations at their data positions [\[R15\]](#R15). The candidate curves show how each deployable model maps target raw values to force.

Look for:

- whether a straight line already explains the data,
- whether nonlinear curves are materially different or only cosmetic,
- whether any curve behaves oddly near endpoints,
- whether selected model is reasonable inside the observed raw range.

### 5.4 `selected_residuals_by_force`

A residual scatter plot for the selected model. NIST recommends residual plots because they can reveal model misspecification that one-number metrics compress away [\[R01\]](#R01).

Look for:

- residuals centered around zero,
- no clear curve or slope with force,
- no direction-specific clusters,
- no single point dominating the error.

### 5.5 `model_comparison_residuals`

Overlaid residual scatter for candidate models.

Look for:

- whether a more complex model removes a repeated residual pattern,
- whether improvement is consistent across force levels,
- whether reduced RMSE comes from fitting one point rather than improving the whole range.

### 5.6 `model_metric_bars`

A bar chart comparing RMSE and max absolute error. Bar plots encode values by bar height and are useful for categorical comparison [\[R16\]](#R16).

Interpretation:

- RMSE estimates typical error magnitude.
- Max absolute error estimates worst displayed/training error.
- A model with slightly lower RMSE but much higher complexity may not be worth deploying.

### 5.7 `model_likelihoods`

A bar chart of `selection_likelihood`. The implementation computes a softmax over negative selection scores among eligible candidates. Softmax exponentiates scores and normalizes them so the resulting values sum to one [\[R13\]](#R13).

Interpretation:

- One dominant bar means the model-selection policy clearly preferred that model.
- Similar bars mean the decision is marginal; prefer the simpler model and improve the protocol before increasing firmware complexity.
- A zero likelihood often means the model was rejected or diagnostic-only.

### 5.8 `robust_huber_weights`

A scatter plot of Huber robust training weights by accepted hold index. Huber regression combines squared loss for small residuals with absolute loss for larger residuals, reducing outlier influence without completely ignoring those samples [\[R06\]](#R06).

Interpretation:

- Weight near 1: hold behaved like an ordinary inlier.
- Weight below 1: hold had a larger residual and was down-weighted during robust training.
- Several low weights: investigate protocol quality before trusting robust fit.

### 5.9 `hysteresis_up_down`

A scatter plot of target raw median versus reference force, grouped by direction.

Interpretation:

- Ascending and descending points overlapping: good reversibility.
- Direction-separated clusters: mechanical hysteresis, fixture load-path effects, or protocol mismatch.
- Separation in target raw but not in reference force: target/fixture issue is more likely.

## 6. Models

### 6.1 `affine_ols`

Formula:

```text
force_N = a * raw + b
```

This is the ordinary least-squares straight-line model. Ordinary least squares chooses coefficients that minimize the sum of squared residuals between observed targets and linear predictions [\[R03\]](#R03). NumPy describes polynomial least-squares fitting as minimizing squared error between fitted polynomial values and data [\[R04\]](#R04).

Use when:

- residuals show no clear curvature,
- the sensor behaves approximately linearly,
- firmware simplicity is important.

Caution: a very high R² can still hide load-dependent residuals. Always inspect residual plots.

### 6.2 `affine_wls`

Formula is still affine:

```text
force_N = a * raw + b
```

The difference is training: holds with higher reference noise receive less influence. In the implementation, reference standard deviation is converted to inverse-sigma weights before polynomial fitting.

Use when:

- all holds are valid but some are noisier than others,
- the reference noise estimate is meaningful,
- the affine model is otherwise adequate.

Caution: weighting cannot fix systematic bias, bad markers, or wrong force labels.

### 6.3 `affine_huber`

Formula exported to firmware remains affine, but the training loop uses Huber robust weights.

Huber regression is less influenced by outliers because it transitions from squared loss for small residuals to absolute loss for large residuals [\[R06\]](#R06). The implementation initializes scale using a MAD-style robust residual scale; MAD is a robust dispersion estimate based on median absolute deviations [\[R12\]](#R12).

Use when:

- one or two holds may be contaminated,
- the rest of the data supports the same line,
- robust weights identify a small number of questionable points.

Caution: if many holds are down-weighted, the issue is probably protocol quality, not model choice.

### 6.4 `quadratic_wls`

Formula:

```text
force_N = a2 * raw^2 + a1 * raw + a0
```

This is a degree-2 polynomial fit. NumPy documents polynomial least-squares fitting and warns that polynomial fits can become poorly conditioned depending on degree and data centering [\[R04\]](#R04). NIST force calibration material notes that second- or third-order polynomial equations are commonly derived from force/response calibration data [\[R18\]](#R18).

Use when:

- residuals show repeatable curvature,
- holdout data confirms the curvature generalizes,
- firmware can implement the polynomial safely.

Caution: with few calibration points, a quadratic can look better on training data but fail cross-validation.

### 6.5 `piecewise_linear_monotone`

This model stores calibration knots and interpolates between them. NumPy defines one-dimensional linear interpolation as evaluating the piecewise-linear interpolant through known data points [\[R05\]](#R05).

Use when:

- the sensor is monotone but not well represented by a line,
- there are enough repeated force levels to define trustworthy knots,
- firmware can enforce calibrated-range limits.

Caution: do not extrapolate beyond the calibrated raw-count range unless explicitly validated.

### 6.6 `odr_affine`

This diagnostic affine model is a **pure-NumPy Deming regression** (a closed-form errors-in-variables fit), conceptually related to orthogonal distance regression but **not** computed with `scipy.odr`. It accounts for uncertainty in both the input (target raw) and output (reference force) variables. Deming regression assumes a known ratio of error variances λ = Var(y-error)/Var(x-error); the implementation estimates λ from the per-hold noise medians and stores it as `variance_ratio_y_over_x`. SciPy's ODR documentation [\[R07\]](#R07) is included as the conceptual reference for errors-in-variables fitting; the orthogonal-regression special case of Deming (λ = 1) is the geometric ODR fit.

Use when:

- target raw values and reference forces both have meaningful uncertainty,
- you want to know whether ordinary least squares is sensitive to x-axis uncertainty.

Caution: in this project it is diagnostic-only by default. If it materially changes the result, investigate uncertainty and reference quality before deploying.

### 6.7 `hysteresis_affine_diagnostic`

This diagnostic fits separate affine relationships for loading directions.

Use when:

- ascending and descending holds differ at the same force,
- the `hysteresis_up_down` plot shows separated clusters,
- reversibility must be quantified before deployment.

Caution: direction-dependent firmware behavior is usually the wrong first fix. Prefer mechanical/protocol investigation unless direction dependence is intentional and validated.

### 6.8 `drift_affine_diagnostic`

Formula:

```text
force_N = a * raw + b + drift_N_per_s * (time - time_center)
```

This model tests whether time explains residuals inside the session.

Use when:

- residuals improve materially after adding time,
- reference or target readings drift over the session,
- creep or warm-up effects are suspected.

Caution: time drift is usually a diagnostic symptom. Prefer stabilizing the hardware/protocol before baking time into firmware.

## 7. Metrics

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

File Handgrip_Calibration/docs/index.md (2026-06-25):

# Handgrip Calibration Documentation

## Summary

- `Handgrip_Calibration` records protocol-guided sessions, fits target raw counts to reference force, generates reports, and validates selected models.
- The canonical primary protocol is `conf/protocol_static_reversible_staircase_v3.yaml`.
- Calibration fits `reference_force_N = f(target_raw_count)`. Firmware `current_units` is a diagnostic convenience channel, not the primary fitting input.

## Component contract

| Contract | Value |
| --- | --- |
| Primary command | `uv run handgrip-cal` |
| Main config | `Handgrip_Calibration/conf/protocol_static_reversible_staircase_v3.yaml` |
| Session output root | `Handgrip_Calibration/data/calibration/<session_id>/` |
| Required upstream streams | `HandgripTarget`, `HandgripReference` |

## Required upstream state

Before running calibration:

1. [docs/workflows/physical-setup.md](../../docs/workflows/physical-setup.md) — PM58 and target in the same force path
2. [Handgrip_Firmware/docs/workflow.md](../../Handgrip_Firmware/docs/workflow.md) — firmware emits D2 frames
3. [docs/workflows/full-live-viewer-quickstart.md](../../docs/workflows/full-live-viewer-quickstart.md) — both streams live

## Reading guide

| I want to… | Read |
| --- | --- |
| Run calibration end to end (preflight → record → fit → report → holdout → apply to firmware/bridge) | [Handgrip_Calibration/docs/workflow.md](workflow.md) |
| Choose a protocol (canonical v3, holdout, legacy labels) | [Handgrip_Calibration/docs/protocols.md](protocols.md) |
| Edit protocol YAML safely | [Handgrip_Calibration/docs/configuration.md](configuration.md) |
| Understand session output files (events, quality, provenance) | [Handgrip_Calibration/docs/recording.md](recording.md) |
| Interpret model selection (metrics, residuals, ranking) | [Handgrip_Calibration/docs/fitting-and-model-selection.md](fitting-and-model-selection.md) |
| Read reports, plots, and JSON artifacts | [Handgrip_Calibration/docs/reports-and-outputs.md](reports-and-outputs.md) |
| Understand every report metric, model, and plot (non-expert reference)  | [Handgrip_Calibration/docs/calibration-report-reference.md](calibration-report-reference.md) |
| Understand CLI-to-module internals | [Handgrip_Calibration/docs/architecture.md](architecture.md) |
| Add protocols, models, or report sections | [Handgrip_Calibration/docs/development.md](development.md) |

## Related docs

- [docs/architecture/stream-contracts.md](../../docs/architecture/stream-contracts.md) — target/reference stream contracts
- [docs/hardware/dual-device-calibration-configuration.md](../../docs/hardware/dual-device-calibration-configuration.md) — recommended acquisition-board + target settings for calibration
- [docs/troubleshooting/calibration-recording.md](../../docs/troubleshooting/calibration-recording.md)

## Minimal command path

Run from the repo root or from `Handgrip_Calibration/` — `conf/...yaml` and
`data/calibration/<session_id>` resolve the same either way, and recorded
sessions always land under `Handgrip_Calibration/data/calibration/`.

```bash
uv run handgrip-cal preflight --config conf/protocol_static_reversible_staircase_v3.yaml
uv run handgrip-cal record    --config conf/protocol_static_reversible_staircase_v3.yaml
uv run handgrip-cal fit       data/calibration/<session_id> \
  --config conf/protocol_static_reversible_staircase_v3.yaml
uv run handgrip-cal report    data/calibration/<session_id>
```

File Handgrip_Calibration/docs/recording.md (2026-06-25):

# Handgrip Calibration Recording

## Summary

- The recording process captures synchronized target/reference LSL data plus protocol events into a session folder.
- Required live streams are `HandgripTarget` and `HandgripReference`.
- The session folder is expected to contain enough raw data, events, and config snapshots to reproduce fitting and reporting.

## Workflow

The preflight, recording, fitting, and validation commands live in [Handgrip_Calibration/docs/workflow.md](workflow.md). This document owns what those steps depend on: session folder structure, preflight acceptance gates, and acquisition-board configuration.

During recording, follow operator prompts exactly. Do not skip baseline/preload/hold steps unless the protocol explicitly allows it.

**The quality of the calibration fit depends entirely on the quality of the recording.** 

## Session IDs

A session ID should uniquely identify a recording.

```text
YYYY-MM-DD_HHMMSS_<protocol_or_label>
```

Expected folder:

```text
Handgrip_Calibration/data/calibration/<session_id>/
```

## Captured files

Exact filenames are implementation-owned, but a complete session should contain these artifact classes:

| Artifact class | Expected files | Purpose |
| --- | --- | --- |
| target data | `target.csv` | Target stream samples and timing. |
| reference data | `reference.csv` | Reference force samples and timing. |
| protocol events | `events.ndjson` | Segment boundaries and operator markers. |
| live quality telemetry | `quality_live.ndjson` | Gap/status/rate diagnostics. |
| config snapshots | copied YAML/config files | Reproducibility. |
| metadata | JSON/YAML manifest | Session identity and protocol metadata.  |

## Preflight acceptance gates

Do not start the protocol until all gates pass:

| Gate | Pass criterion |
| --- | --- |
| Reference live rate | `498–500 Hz` preferred, `>= 495 Hz` minimum |
| Target live rate | approximately `85–105 Hz` |
| Reference max gap | below `0.020 s` |
| Target max gap | below `0.100 s` |
| Reference zero noise | low enough that a 3 s hold passes `max_hold_reference_std_N: 0.5` |
| Force response sign | reference and target move monotonically in the same physical direction |
| No target parser drops | `target_status` does not show persistent not-ready/overflow conditions |
| Reference sync offset  | measured and compensated via `manual_reference_shift_s` (see below) |

These thresholds correspond to the `QualityConfig` defaults in the protocol YAML:

```yaml
quality:
  reference_expected_hz: 500
  reference_min_hz: 495
  reference_max_gap_s: 0.02
  target_expected_hz_min: 85
  target_expected_hz_max: 105
  target_max_gap_s: 0.1
  max_hold_reference_std_N: 0.5
  max_hold_reference_slope_N_per_s: 0.2
  max_baseline_drift_N_per_min: 0.5
  min_hold_target_samples: 20
  min_hold_reference_samples: 100
```

### Capture preflight and reference-offset measurement

The reference stream is stamped at GUI read time and lags the directly-connected target by a stable relay offset (see [docs/architecture/timestamping-and-synchronization.md](../../docs/architecture/timestamping-and-synchronization.md)). Before recording — and after **any** change to the physical or runtime setup (cabling, ports, host, baud, rates) — run the calibration preflight to validate the capture and obtain the offset:

**1. Enable diagnostics in the viewer:** 

- Set `diagnostics.enabled=true` in the viewer config and launching the viewer.

**2. Run the preflight script against a short diagnostics capture:**

```bash
# from the Handgrip_Calibration directory, against a short diagnostics capture
uv run python scripts/calibration_preflight.py \
  --viewer-session ../diagnostics/<ts> \
  --bridge-target-csv ../LSL_Bridge/data/target_*.csv \
  --bridge-reference-csv ../LSL_Bridge/data/reference_*.csv \
  --gui-ndjson ../RS485_GUI/logs/raw_signal.ndjson
```

It checks that GUI/Bridge/Viewer diagnostic + logging config is correct and the logs are from the current binary, confirms the timing issues are absent, and prints the exact `manual_reference_shift_s` (plus the file and key) to set in `LSL_Viewer/conf/config.yaml`. 

The shift is a host-read-latency compensation, not acquisition truth, so it must be re-measured per setup.

## Recommended acquisition board configuration for recording

Before recording, ensure the acquisition board is configured for clean calibration-quality reference output. Key settings:

| Setting | Recommended value | Why |
| --- | --- | --- |
| Internal sampling (`100.SP`) | `640 Hz` | Preserves timing detail for the reference force trace |
| ADC gain (`101.GA`) | `128B` | Matches PM58 sensitivity to ADC resolution |
| Median filter (`102.ME`) | `3` | Suppresses impulse outliers without adding significant lag |
| Average filter (`103.rV`) | `5` | Modest smoothing while preserving dynamics |
| Unit (`105.uN`) | `N` | Ensures reference force is in Newtons, consistent with reports |
| Creep tracking (`400.CV`) | `0` | Disabled — hidden correction distorts calibration data |
| Dynamic tracking (`402.tV`)  | `0` | Disabled — can distort the force trace |
| Auto-zero (`409.AZ`) | `0` | Disabled — prevents silent drift correction during session |
| Power-on zero (`406.PZ`) | `0` | Disabled — prevents baseline shift at startup |
| RS485 mode (`504.AS`) | `1` (Active-Send) | Recommended 500 Hz push mode |
| Active-Send rate (`505.AF`)  | `500 Hz` | High enough to preserve timing detail |
| Baud (`501.br`) | `460800` | Required for 500 Hz Active-Send |

For the full per-register rationale behind these recommended values, see [docs/hardware/dual-device-calibration-configuration.md](../../docs/hardware/dual-device-calibration-configuration.md). For the complete board menu reference and commissioning sequence, see [docs/hardware/acquisition-board-reference.md](../../docs/hardware/acquisition-board-reference.md).

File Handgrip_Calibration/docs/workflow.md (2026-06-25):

# Workflow - From init to firmware deployment

Assumption: `RS485_GUI` and `LSL_Bridge` are already alive, and `LSL_Bridge` is publishing `HandgripTarget` and `HandgripReference`. That matches the architecture: `LSL_Bridge` is the canonical publisher for both target/reference LSL streams, while `Handgrip_Calibration` records sessions and fits `reference_force_N = f(target_raw_count)`. 

The canonical stream/config invariants are:
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

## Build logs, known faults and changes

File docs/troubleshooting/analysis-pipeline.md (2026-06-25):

# Analysis Pipeline Troubleshooting

## Summary

**Symptoms covered:** Manifest errors, missing stage outputs, invalid filter candidates

**Prerequisite:** [docs/troubleshooting/calibration-recording.md](calibration-recording.md) — confirm calibration sessions and exported CSV files exist before debugging analysis inputs.

Use this guide when `Handgrip_Analysis` cannot load inputs, run stages, or produce expected reports/filter recommendations.

## Symptom: manifest errors

### Likely causes

| Cause | Check | Fix |
| --- | --- | --- |
| Source file missing | manifest paths | Use repo-relative or component-relative paths consistently. |
| Column name mismatch | input CSV headers | Update manifest channel mapping. |
| Wrong session ID | manifest/session folder | Copy exact session ID from calibration output. |
| Unsupported data type | loader errors | Convert/export to expected CSV/session format. |
| Missing protocol metadata | report cannot group trials | Use calibration session with event markers. |

## Symptom: missing stage outputs

### Likely causes

| Cause | Fix |
| --- | --- |
| Stage disabled in config | Enable stage or run specific stage command. |
| Output directory changed | Inspect config and command override. |
| Stage failed silently in batch | Run stage individually with verbose logging. |
| Required input absent | Fix manifest or upstream export. |
| Old output read by mistake | Delete/rename output folder or use new run ID. |

## Symptom: invalid filter candidates

### Common causes

| Cause | Explanation | Fix |
| --- | --- | --- |
| Cutoff above Nyquist | Sampling rate too low for requested cutoff | Lower cutoff or confirm sampling rate. |
| Missing raw baseline | Candidate comparison lacks reference | Include identity/raw candidate. |
| Filter unstable | Bad order/cutoff/family combination | Use validated filter families. |
| Latency not considered | Smooth trace but bad timing | Include lag/phase metrics. |
| Recommendation target unclear | Unsure whether to apply in bridge/viewer/firmware | Document deployment target in Stage 6 report. |

## Diagnostic workflow

1. Run `--help` for available CLI entry points (these can be run from the
   repo root or from `Handgrip_Analysis/`):

```bash
uv run ha-run-all --help
uv run ha-stage --help
uv run ha-stage6-design --help
uv run ha-stage6-review --help
```

2. Validate manifest file paths.
3. Run the failing stage individually.
4. Inspect logs/output folder.
5. Check required columns and sampling rate.
6. For Stage 6, inspect candidate table and recommendation file.

## Expected Stage 6 artifacts

Typical artifacts include:

- `filter_comparison.csv`,
- `metrics.json`,
- Stage 6 report Markdown/HTML,
- plots,
- `lsl_bridge_processing_recommendation.yaml` or equivalent recommendation file.

**Related docs:** [docs/workflows/handgrip-analysis.md](../workflows/handgrip-analysis.md), [Handgrip_Analysis/docs/stages.md](../../Handgrip_Analysis/docs/stages.md), [Handgrip_Analysis/docs/filter-design.md](../../Handgrip_Analysis/docs/filter-design.md)

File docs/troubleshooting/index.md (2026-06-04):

# Troubleshooting Index

## Summary

Troubleshooting is symptom-first. Start with the symptom you see, validate the owner component, then follow the linked workflow or component doc.

## Symptom map

| Symptom | Start here |
| --- | --- |
| No board display, wrong load sign, unstable reading, overload | [docs/troubleshooting/hardware-and-wiring.md](hardware-and-wiring.md) |
| No serial port, wrong A/B, baud mismatch, no Active-Send frames | [docs/troubleshooting/serial-and-rs485.md](serial-and-rs485.md) |
| Streams not visible, wrong names, stale outlets | [docs/troubleshooting/lsl-streams.md](lsl-streams.md) |
| XY delay, reference lag, display-only shift vs real timestamp issue | [docs/troubleshooting/viewer-lag-or-xy-delay.md](viewer-lag-or-xy-delay.md) |
| Missing target/reference CSV, failed preflight, bad session ID | [docs/troubleshooting/calibration-recording.md](calibration-recording.md) |
| Manifest errors, missing stage outputs, invalid filter candidates | [docs/troubleshooting/analysis-pipeline.md](analysis-pipeline.md) |

## General rule

Validate hardware and stream contracts before editing implementation code.

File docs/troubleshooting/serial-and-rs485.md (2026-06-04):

# Serial and RS485 Troubleshooting

## Summary
**Symptoms covered:** No serial port, wrong A/B, baud mismatch, no Active-Send frames

**Prerequisite:** [docs/troubleshooting/hardware-and-wiring.md](hardware-and-wiring.md) — confirm board powers on and force path is valid before debugging serial.

Use this guide when the host PC cannot see the Arduino target or USB-RS485 adapter, or when `RS485_GUI` cannot receive acquisition-board frames.

## Symptom: no serial port

### Checks

```bash
ls -l /dev/serial/by-id/ 2>/dev/null || true
ls -l /dev/ttyUSB* /dev/ttyACM* 2>/dev/null || true
dmesg | tail -80
```

### Likely causes

| Cause | Fix |
| --- | --- |
| USB cable is power-only | Use a known data-capable USB cable. |
| Device permissions | Add user to `dialout` or use udev rules; re-login. |
| Adapter not enumerating | Try another USB port/cable. |
| Port occupied | Close serial monitor, GUI, bridge, or other process using the port. |

## Symptom: wrong A/B wiring

### Signs

- Adapter appears, but no valid RS485 frames arrive.
- Board display works locally.
- Modbus polling times out.
- Active-Send parser sees nothing or continuous malformed data.

### Fix

Power down if required by lab practice, then swap A/B on the RS485 adapter side and retry.

Typical mapping:

| Board | Adapter |
| ----- | --- |
| A+ | A / D+  |
| B- | B / D-  |

## Symptom: baud mismatch

### Signs

- Garbled serial output.
- Parser receives bytes but no valid frames.
- Modbus CRC errors.
- Active-Send payloads appear with wrong length or invalid values.

### Fix

Ensure acquisition board communication menu and `RS485_GUI/config/config.yaml` agree on:

- baud rate,
- parity,
- stop bits,
- device address when using Modbus,
- Active-Send enabled/disabled state.

## Symptom: no Active-Send frames

### Likely causes

| Cause | Fix |
| --- | --- |
| Active-Send not enabled on board | Enable vendor Active-Send mode from board menu. |
| Wrong output rate | Set a supported rate, typically 500 Hz for calibration profile. |
| Wrong serial profile | Align baud/parity/stop bits. |
| Wrong parser profile | Update `RS485_GUI/config/config.yaml`. |
| A/B swapped | Swap RS485 pair and retry. |

## Fallback path

If Active-Send is unstable, validate the chain with Modbus RTU polling first. Polling is slower and introduces jitter on the sampling rate, but easier to debug.

**Related docs:** [docs/workflows/target-only-quickstart.md](../workflows/target-only-quickstart.md), [docs/workflows/reference-only-quickstart.md](../workflows/reference-only-quickstart.md), [RS485_GUI/docs/active-send-and-modbus.md](../../RS485_GUI/docs/active-send-and-modbus.md)

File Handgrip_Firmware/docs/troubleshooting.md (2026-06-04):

# Handgrip Firmware Troubleshooting

## Summary

Use this document when firmware build/upload or target serial validation fails.

Most firmware-side handoff failures fall into one of these buckets:

1. PlatformIO project opened from the wrong directory.
2. Wrong Arduino Nano bootloader/board environment.
3. Serial port selection or permissions problem.
4. Firmware uploaded but no valid D2 output appears.
5. HX711 not wired or not ready.
6. FIFO/status bits indicate runtime pressure.
7. Firmware constants produce invalid `current_units`.

## Fast triage table

| Symptom | Likely cause | First action |
| --- | --- | --- |
| PlatformIO cannot find project | VS Code opened `Handgrip_Firmware/` instead of repo root | Reopen repository root. |
| Build cannot find `config.h` | root `platformio.ini` not loaded or include path wrong | Confirm root `platformio.ini`. |
| Upload sync error | Wrong bootloader or wrong serial port | Confirm `board = nanoatmega328`; select correct port. |
| Permission denied on `/dev/ttyUSB*` | Linux serial permissions | Add user to `dialout` or use appropriate udev/permissions flow. |
| Serial monitor blank | wrong port, wrong baud, firmware not running | Monitor at `115200`; reset board; confirm target port. |
| Garbled serial output | baud mismatch or wrong device | Confirm `SERIAL_BAUD_RATE` and monitor speed. |
| No D2 lines | old firmware, wrong monitor device, firmware stuck, HX711 not ready | Rebuild/upload and inspect status/metadata. |
| `current_units` is `nan` | invalid scale factor | Check `SCALE_FACTOR`; use `raw_count` for calibration. |
| Frequent FIFO overflow status | serial/loop cannot drain samples fast enough | Check host monitor/bridge load and FIFO depth. |

## Upload errors

### Symptom

```text
avrdude: stk500_recv(): programmer is not responding
```

### Likely causes

- wrong serial port,
- serial monitor already open,
- wrong bootloader profile,
- bad USB cable,
- board not powered or not resettable.

### Fix workflow

1. Close serial monitor and any bridge process using the port.
2. Identify the target device:

```bash
ls -l /dev/serial/by-id/ 2>/dev/null || true
ls -l /dev/ttyUSB* /dev/ttyACM* 2>/dev/null || true
```

3. Confirm `platformio.ini` uses:

```ini
board = nanoatmega328
```

4. Upload explicitly:

```bash
pio run -e nanoatmega328 -t upload --upload-port /dev/ttyUSB_TARGET
```

## Old bootloader mismatch

The expected board environment is:

```ini
[env:nanoatmega328]
board = nanoatmega328
```

Do not switch to a new-bootloader Nano environment unless the physical board is replaced and validated.

Failure pattern:

- compile succeeds,
- upload fails with sync/timeout errors,
- different board profiles behave inconsistently.

Fix:

- keep `nanoatmega328`,
- use explicit upload port,
- verify cable and board reset behavior.

## Serial port permissions

### Symptom

```text
Permission denied: /dev/ttyUSB0
```

### Linux checks

```bash
groups
ls -l /dev/ttyUSB* /dev/ttyACM* 2>/dev/null || true
```

Typical fix on Debian/Ubuntu/Linux Mint-style systems:

```bash
sudo usermod -aG dialout "$USER"
```

Then log out and log back in.

Temporary test only:

```bash
sudo chmod a+rw /dev/ttyUSB0
```

Do not rely on temporary permissions as the permanent lab setup.

## No D2 output

### Symptom

Serial monitor opens but no valid D2 lines appear.

### Checks

1. Confirm baud:

```bash
pio device monitor -e nanoatmega328 -b 115200
```

2. Press/reset the Arduino and look for:

```text
M2,2,...
```

3. Confirm the monitor is attached to the Arduino, not the USB-RS485 adapter.
4. Rebuild/upload current firmware.
5. Inspect HX711 wiring and power.

### Possible causes

| Cause | Evidence | Fix |
| --- | --- | --- |
| wrong serial port | no M2; RS485 noise/board data instead | use `/dev/serial/by-id/` target path. |
| wrong baud | garbled text | use `115200`. |
| old firmware | output does not use D2 | rebuild/upload. |
| firmware reset loop | repeated M2, no stable D2 | inspect power/wiring/source changes.  |
| HX711 never ready | M2 appears but no samples or status issues | inspect HX711 pins/load cell wiring.  |

## Status-bit diagnosis

| Status bit | Meaning | Likely cause | Action |
| ---: | --- | --- | --- |
| `0x0000` | OK | Normal sample | Continue. |
| `0x0001` | FIFO overflow | main loop/serial emission cannot keep up | reduce host blocking, close slow monitor, inspect bridge load, consider FIFO depth only after measuring. |
| `0x0002` | HX711 not ready | timer tick occurred before HX711 conversion ready | occasional is expected; persistent means rate/wiring/HX711 issue. |
| `0x0004` | scale invalid | `SCALE_FACTOR == 0.0F` or invalid unit conversion | fix `SCALE_FACTOR`; trust `raw_count` over `current_units`. |

## Raw count does not change under force

Likely causes:

- load cell not wired to HX711,
- HX711 data/clock pins wrong,
- target mechanical force path not loading the sensor,
- board powered but target sensor not powered,
- wrong device is being monitored.

Validation:

```bash
pio device monitor -e nanoatmega328 -b 115200
```

Watch `raw_count` while applying small force. If `raw_count` is flat, this is not a calibration-model problem yet; validate mechanics and HX711 wiring first.

## `current_units` looks wrong but `raw_count` works

This usually means firmware constants are not calibrated yet.

Expected during early bring-up:

```c
#define SCALE_FACTOR 1.0F
#define SCALE_OFFSET 0.0F
```

In this state, `current_units` is only a placeholder/sanity value. Continue calibration with `raw_count` and update firmware constants only after an accepted report/holdout validation.

## Bridge cannot parse target output

If `LSL_Bridge` drops target lines:

1. Open serial monitor directly.
2. Confirm D2 field count:

```text
D2,<seq>,<timestamp_us>,<raw_count>,<current_units>,<status>
```

3. Confirm there are no extra commas or missing fields.
4. Confirm bridge parser docs and firmware docs agree.
5. Run bridge parser tests if available.

## Stop conditions

Stop firmware-side debugging and escalate before calibration if:

- upload cannot be made reproducible,
- serial output is not D2,
- `raw_count` is static under real force,
- status bits are persistently nonzero and unexplained,
- bridge parser fails on direct firmware output,
- firmware constants were changed without documenting the build.

## Useful commands

```bash
# Build
pio run -e nanoatmega328

# Upload
pio run -e nanoatmega328 -t upload

# Monitor
pio device monitor -e nanoatmega328 -b 115200

# Identify serial devices
ls -l /dev/serial/by-id/ 2>/dev/null || true
ls -l /dev/ttyUSB* /dev/ttyACM* 2>/dev/null || true

```

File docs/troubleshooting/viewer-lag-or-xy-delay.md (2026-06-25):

# LSL Viewer Lag or XY Delay Troubleshooting

**Symptoms covered:** XY delay, reference lag, display-only shift vs real timestamp issue

**Prerequisite:** [docs/troubleshooting/lsl-streams.md](lsl-streams.md) — confirm both streams are visible and not stale before diagnosing viewer timing.

## Summary

A delayed XY plot is a symptom to diagnose, not automatic proof that recorded data is delayed. Separate display/render issues from timestamping/acquisition issues before changing code.

## Symptom: XY delay grows over time

### Likely causes

| Cause | Why | Check |
| --- | --- | --- |
| Reference interpolation window mismatch | Target/reference rates differ | [LSL_Viewer/docs/xy-correlation.md](../../LSL_Viewer/docs/xy-correlation.md) settings. |
| Timestamp anchor drift | Device clock and host time diverge | [LSL_Bridge/docs/timestamping.md](../../LSL_Bridge/docs/timestamping.md). |
| Buffer pruning bug | Viewer keeps unmatched old samples | Viewer alignment tests/logs. |
| Display render backlog | Browser cannot keep up | Compare saved data vs visual plot. |

### Reference lag only in XY plot

If time-series plots react live but XY correlation lags, suspect viewer alignment/interpolation logic before changing acquisition or bridge code. Check: XY alignment mode, target/reference signal labels, interpolation gap threshold, max XY points, manual reference shift, render downsampling.

## Symptom: display-only shift vs real timestamp issue

Use this decision table:

| Observation | Likely class |
| --- | --- |
| Saved CSV target/reference align correctly, but browser XY lags | viewer display/alignment issue. |
| Saved CSV and viewer both show delay | timestamp/acquisition issue. |
| Only reference stream lags | RS485 GUI, IPC, or reference timestamping issue. |
| Only target stream lags | firmware serial, bridge parser, or target timestamping issue. |

## Diagnostic workflow

1. Confirm `RS485_GUI` live value reacts to force.
2. Confirm target firmware D2 `raw_count` reacts to force.
3. Confirm `LSL_Bridge` publishes both streams.
4. Compare viewer time-series plots.
5. Compare viewer XY plot.
6. Record short calibration/preflight data.
7. Inspect saved target/reference timestamps.
8. Only then change viewer or bridge alignment settings.

## Common fixes

| Fix | Use when |
| --- | --- |
| Reduce viewer max points | Browser/render lag dominates. |
| Adjust XY interpolation mode | XY only is misaligned. |
| Use tail-aligned LSL mode | Comparing most recent target/reference tails is preferred. |
| Reanchor target timestamping | Device clock drift exceeds bridge threshold. |
| Validate RS485 profile | Reference stream itself is delayed or bursty. |
| Set `manual_reference_shift_s` | Saved data shows a stable reference offset (relay latency). Measure it with the calibration preflight (below). |

## Measure and compensate the reference offset

The reference path (`board → RS485 → RS485_GUI → IPC → LSL_Bridge`) is stamped at GUI read time and lags the directly-connected target by a stable **relay offset** — see [docs/architecture/timestamping-and-synchronization.md](../architecture/timestamping-and-synchronization.md). When the saved CSVs (not just the browser) show that offset, compensate it with a constant viewer shift rather than changing acquisition.

Run the calibration preflight (from the `Handgrip_Calibration` directory):

```bash
uv run python scripts/calibration_preflight.py \
  --viewer-session ../diagnostics/<ts> \
  --bridge-target-csv ../LSL_Bridge/data/target_*.csv \
  --bridge-reference-csv ../LSL_Bridge/data/reference_*.csv \
  --gui-ndjson ../RS485_GUI/logs/raw_signal.ndjson
```

It validates that the capture config/logs are correct, confirms the ratchet/throughput/jitter issues are absent, and — when the offset is stable — prints the exact `manual_reference_shift_s` plus the file and key to set in `LSL_Viewer/conf/config.yaml` (`viewer.xy_correlation.time_alignment`). Re-measure after any setup change (cabling, ports, host, baud, rates); the offset is physical.

**Related docs:** [LSL_Viewer/docs/xy-correlation.md](../../LSL_Viewer/docs/xy-correlation.md), [docs/architecture/timestamping-and-synchronization.md](../architecture/timestamping-and-synchronization.md), [LSL_Bridge/docs/timestamping.md](../../LSL_Bridge/docs/timestamping.md)

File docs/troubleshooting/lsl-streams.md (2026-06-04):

# LSL Streams Troubleshooting

## Summary

**Symptoms covered:** Streams not visible, wrong names

**Prerequisite:** [docs/troubleshooting/serial-and-rs485.md](serial-and-rs485.md) — confirm both serial devices enumerate and acquisition-board frames arrive before debugging LSL streams.

Use this guide when `LSL_Viewer` or `Handgrip_Calibration` cannot find `HandgripTarget`, `HandgripReference`, marker streams, or component event streams.

## Symptom: streams not visible

### Likely causes

| Cause | Check | Fix |
| --- | --- | --- |
| `LSL_Bridge` not running | Terminal/logs | Start bridge after upstream producers. |
| Target serial missing | Bridge target logs | Validate firmware D2 output. |
| Reference IPC missing | Bridge reference logs | Start `RS485_GUI` and confirm IPC topic. |
| Firewall/network issue | LSL discovery tools | Keep processes on same host/network; check firewall. |
| Wrong stream names | Configs/docs differ | Align names with [docs/architecture/stream-contracts.md](../architecture/stream-contracts.md). |

### Stale outlets

If streams appear with wrong names or duplicates, kill stale outlets:

1. Stop viewer and calibration clients.
2. Stop `LSL_Bridge`.
3. Stop `RS485_GUI` if reference stream is involved.
4. Restart in canonical order:

```bash
cd RS485_GUI && uv run rs485-gui
cd ../LSL_Bridge && uv run lsl-bridge
cd ../LSL_Viewer && uv run lsl-viewer
```

5. Re-run calibration preflight.

## Symptom: wrong stream names

Canonical names:

| Stream | Producer |
| --- | --- |
| `HandgripTarget` | `LSL_Bridge` |
| `HandgripReference` | `LSL_Bridge` |
| `HandgripComponentEvents` | `LSL_Bridge` |
| `HandgripCalibrationMarkers` | `Handgrip_Calibration` |

If a component uses different names, update all relevant configs or document the intentional migration.

**Related docs:** [docs/architecture/stream-contracts.md](../architecture/stream-contracts.md), [LSL_Bridge/docs/stream-contracts.md](../../LSL_Bridge/docs/stream-contracts.md), [docs/workflows/full-live-viewer-quickstart.md](../workflows/full-live-viewer-quickstart.md)

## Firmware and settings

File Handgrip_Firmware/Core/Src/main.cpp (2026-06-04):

/**
 ******************************************************************************
 * @file    main.cpp
 * @author  Nicolas Schiappacasse <nicolaschiappacase@gmail.com>
 * @date    05/2026
 * @brief   Calibration-ready Arduino Nano + HX711 acquisition firmware.
 *
 * Breaking schema upgrade:
 *   - Legacy `D,<seq>,<timestamp_us>,<value>` output was removed.
 *   - The firmware now emits explicit D2 frames with raw counts, interpreted
 *     units, sequence number, device timestamp, and status bits.
 *   - A metadata M2 line is emitted at boot so the LSL bridge/session manifest
 *     can capture firmware schema, constants, and expected HX711 rate.
 *
 * The firmware remains deliberately simple: acquire deterministic raw samples,
 * timestamp them with micros(), and send them over UART. Calibration session
 * ownership, markers, segmentation, fitting, and reports belong to the host-side
 * Handgrip_Calibration module.
 ******************************************************************************
 */

/** @addtogroup HandGrip
 * @{
 */
/** @addtogroup Application
 * @{
 */
/** @addtogroup Main
 * @{
 */
/**
 * @defgroup PUBLIC_Definitions          PUBLIC constants
 * @defgroup PUBLIC_Macros               PUBLIC macros
 * @defgroup PUBLIC_Types                PUBLIC data-types
 * @defgroup PUBLIC_API                  PUBLIC API
 * @defgroup PUBLIC_WEAK                 PUBLIC Weak API
 * @defgroup PRIVATE_TUNABLES            Private compile-time tunables
 * @defgroup PRIVATE_Definitions         Private constants
 * @defgroup PRIVATE_Macros              Private macros
 * @defgroup PRIVATE_Types               Private data-types
 * @defgroup PRIVATE_Data                Private data / variables
 * @defgroup PRIVATE_Functions           Private functions
 * @defgroup PRIVATE_Weak                Private Weak functions
 */

#include <Arduino.h>
#include <stdlib.h>
#include <stdint.h>

#include "HX711.h"      /* https://github.com/RobTillaart/HX711 */
#include "TimerOne.h"   /* https://github.com/PaulStoffregen/TimerOne */

#include "fifo_buffer.h"  
#include "config.h"


/*----------------------------------------------------------------------------*/
/** @ingroup PRIVATE_TUNABLES                                                  */
/**@{                                                                         */
/*----------------------------------------------------------------------------*/

/** Pin mapping for HX711 scale */
#define GPIO_DATA_PIN    2U
#define GPIO_CLOCK_PIN   3U

/** FIFO depth for interrupt-to-loop handoff. */
#define MAX_FIFO_SIZE                  80U


/** @} */
/*----------------------------------------------------------------------------*/
/** @ingroup PRIVATE_Definitions                                               */
/**@{                                                                         */
/*----------------------------------------------------------------------------*/

/** @} */
/*----------------------------------------------------------------------------*/
/** @ingroup PRIVATE_Macros                                                    */
/**@{                                                                         */
/*----------------------------------------------------------------------------*/

/** @} */
/*----------------------------------------------------------------------------*/
/** @ingroup PRIVATE_Types                                                     */
/**@{                                                                         */
/*----------------------------------------------------------------------------*/

/**
 * @brief Sensor sample structure.
 */
typedef struct
{
    int32_t  raw_count;       /**< HX711 raw ADC count, before scale/offset. */
    float    current_units;   /**< Convenience engineering value from config constants. */
    uint32_t timestamp_us;    /**< Device-local micros() timestamp. */
    uint32_t seq;             /**< Monotonic sequence number. */
    uint16_t status;          /**< HANDGRIP_STATUS_* bitfield. */
} SensorSample;

/** @} */
/*----------------------------------------------------------------------------*/
/** @cond DOXYGEN_SKIP_PROTOTYPES */
/* Prototype for the interrupt handler */
void sample_scale(void);

/* Prototypes for utility functions */
static float _raw_to_units(int32_t raw_count);
static void _emit_metadata(void);
static void _emit_sample(const SensorSample &sample);
/** @endcond */
/*----------------------------------------------------------------------------*/
/** @ingroup PRIVATE_Data                                                      */
/**@{                                                                         */
/*----------------------------------------------------------------------------*/

/** HX711 scale object */
HX711 _scale;

/** Sensor sample FIFO buffer */
FIFObuf<SensorSample>  _sensor_fifo(MAX_FIFO_SIZE);
volatile uint32_t _seq = 0;
volatile uint16_t _sticky_status = HANDGRIP_STATUS_OK;

/** @} */
/*----------------------------------------------------------------------------*/
/** @ingroup PUBLIC_API                                                        */
/**@{                                                                         */
/*----------------------------------------------------------------------------*/

/**
 * @brief Setup the application.
 */
void setup()
{
    /* Serial port */
    Serial.begin(SERIAL_BAUD_RATE);

    /* HX711 scale object */
    _scale.begin(GPIO_DATA_PIN, GPIO_CLOCK_PIN);

    /* Keep HX711 offset/scale configured for operator sanity, but never rely on
     * get_units() for calibration. D2 always carries raw_count explicitly. */
    _scale.set_scale(SCALE_FACTOR);
    _scale.set_offset(SCALE_OFFSET);

    /* Emit metadata (M2) at boot so the LSL_Bridge/Handgrip_Calibration can
     * capture firmware schema, constants, and expected HX711 rate. */
    _emit_metadata();

    /* Set Timer based Interrupt for sampling */
    Timer1.initialize(SAMPLING_PERIOD_US);
    Timer1.attachInterrupt(sample_scale);

}


/**
 * @brief Main loop.
 * @note This function runs magnitudes faster than the sampling interrupt.
 */
void loop()
{
    SensorSample sample = _sensor_fifo.pop();
    if (sample.timestamp_us == 0U)
    {
        /* Arduino equivalent of "continue" for the main loop(). */
        return;  
    }
    _emit_sample(sample);
}

/** @} */
/*----------------------------------------------------------------------------*/
/* ====================== Interrupt Service Routine ======================== */

/**
 * @brief Timer ISR: non-blocking HX711 sample capture.
 * @note The ISR never waits for the ADC. 
 * It records a status bit when the HX711 is not ready and returns immediately. 
 * This keeps loop latency predictable and makes timing irregularity visible 
 * instead of hidden by blocking reads.
 */
void sample_scale(void)
{
    if (!_scale.is_ready())
    {
        _sticky_status |= HANDGRIP_STATUS_HX711_NOTREADY;
        return;
    }

    SensorSample sample;
    sample.timestamp_us = micros();
    sample.raw_count = _scale.read();
    sample.current_units = _raw_to_units(sample.raw_count);
    sample.seq = _seq++;
    sample.status = _sticky_status;

    if (isnan(sample.current_units))
    {
        sample.status |= HANDGRIP_STATUS_SCALE_INVALID;
    }

    uint8_t ok = _sensor_fifo.push(sample);
    if (!ok)
    {
        _sticky_status |= HANDGRIP_STATUS_FIFO_OVERFLOW;
    }
    else
    {
        _sticky_status = HANDGRIP_STATUS_OK;
    }
}

/* ====================== Utility Functions ================================ */

/* Emit boot/build metadata consumed by LSL_Bridge. */
static void _emit_metadata(void)
{
    Serial.print("M2,");
    Serial.print(HANDGRIP_PAYLOAD_SCHEMA);
    Serial.print(",");
    Serial.print(HANDGRIP_FIRMWARE_VERSION);
    Serial.print(",");
    Serial.print(HANDGRIP_FIRMWARE_GIT_SHA);
    Serial.print(",");
    Serial.print(HX711_EXPECTED_OUTPUT_RATE_HZ, 3);
    Serial.print(",");
    Serial.print(SCALE_FACTOR, 9);
    Serial.print(",");
    Serial.print(SCALE_OFFSET, 3);
    Serial.print(",");
    Serial.print(HANDGRIP_FORCE_UNIT);
    Serial.print("\n");
}

/* Emit one strict D2 data record. */
static void _emit_sample(const SensorSample &sample)
{
    Serial.print("D2,");
    Serial.print(sample.seq);
    Serial.print(",");
    Serial.print(sample.timestamp_us);
    Serial.print(",");
    Serial.print(sample.raw_count);
    Serial.print(",");
    if (isnan(sample.current_units))
    {
        Serial.print("nan");
    }
    else
    {
        Serial.print(sample.current_units, 6);
    }
    Serial.print(",");
    Serial.print(sample.status);
    Serial.print("\n");
}

/* Convert raw HX711 counts to current engineering units for sanity display. */
static float _raw_to_units(int32_t raw_count)
{
    if (SCALE_FACTOR == 0.0F)
    {
        return NAN;
    }
    return ((float)raw_count - SCALE_OFFSET) / SCALE_FACTOR;
}
/** @ingroup PRIVATE_Weak                                                      */
/**@{                                                                         */
/*----------------------------------------------------------------------------*/

/*----------------------------------------------------------------------------*/
/** @} */
/*--->> END: Private Functions <<---------------------------------------------*/

/** @} */
/** @} */
/** @} */

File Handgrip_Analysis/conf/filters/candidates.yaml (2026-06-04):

# Handgrip_Analysis Stage 6 production-real-time filter candidates
# Active filters are intentionally restricted to filters that map directly to
# LSL_Bridge processing.filters and are evaluated with the same causal per-sample
# implementation used for production streaming.

metadata:
  schema_version: 2
  intended_stage: stage6
  generated_for: Handgrip_Analysis existing 20260402 and 20260512 trials
  target_sampling_rate_hz_observed: 100.0
  primary_search_region_hz:
  - 4.0
  - 12.0
  fidelity_biased_region_hz:
  - 15.0
  - 25.0
  lsl_bridge_primary_deployable_family: butterworth_lowpass_2nd
  notes:
  - 'This file is production-biased: active candidates avoid diagnostic high-pass/band-pass filters that could corrupt absolute
    force baselines.'
  - Notch filters are kept in metadata below as diagnostic candidates, but not included in the active filters list because
    current Stage 2 evidence does not show a stable replicated line component.
  - If future Stage 5 interference trials prove a stable narrowband line, move the relevant notch or notch+lowpass diagnostic
    candidate into `filters:` and re-run Stage 6.
  - Active filters use LSL_Bridge production-real-time type names and causal per-sample semantics.
  production_realtime_contract: active filters must map 1:1 to LSL_Bridge processing.filters entries
filters:
- name: identity
  type: identity
  rationale: Baseline reference; required to quantify whether filtering improves enough to justify deployment.
- name: butter_lowpass_3hz
  type: butterworth_lowpass_2nd
  cutoff_hz: 3.0
  family: primary_lowpass_sweep
  deployment_priority: aggressive_smoothing
  sample_rate_hz: 100.0
  q: 0.7071067811865476
  reset_on_gap_s: 1.0
  min_dt_s: 1.0e-06
- name: butter_lowpass_4hz
  type: butterworth_lowpass_2nd
  cutoff_hz: 4.0
  family: primary_lowpass_sweep
  deployment_priority: aggressive_smoothing
  sample_rate_hz: 100.0
  q: 0.7071067811865476
  reset_on_gap_s: 1.0
  min_dt_s: 1.0e-06
- name: butter_lowpass_5hz
  type: butterworth_lowpass_2nd
  cutoff_hz: 5.0
  family: primary_lowpass_sweep
  deployment_priority: balanced_noise_reduction
  sample_rate_hz: 100.0
  q: 0.7071067811865476
  reset_on_gap_s: 1.0
  min_dt_s: 1.0e-06
- name: butter_lowpass_6hz
  type: butterworth_lowpass_2nd
  cutoff_hz: 6.0
  family: primary_lowpass_sweep
  deployment_priority: balanced_noise_reduction
  sample_rate_hz: 100.0
  q: 0.7071067811865476
  reset_on_gap_s: 1.0
  min_dt_s: 1.0e-06
- name: butter_lowpass_7hz
  type: butterworth_lowpass_2nd
  cutoff_hz: 7.0
  family: primary_lowpass_sweep
  deployment_priority: balanced_noise_reduction
  sample_rate_hz: 100.0
  q: 0.7071067811865476
  reset_on_gap_s: 1.0
  min_dt_s: 1.0e-06
- name: butter_lowpass_8hz
  type: butterworth_lowpass_2nd
  cutoff_hz: 8.0
  family: primary_lowpass_sweep
  deployment_priority: balanced_default_region
  sample_rate_hz: 100.0
  q: 0.7071067811865476
  reset_on_gap_s: 1.0
  min_dt_s: 1.0e-06
- name: butter_lowpass_9hz
  type: butterworth_lowpass_2nd
  cutoff_hz: 9.0
  family: primary_lowpass_sweep
  deployment_priority: balanced_default_region
  sample_rate_hz: 100.0
  q: 0.7071067811865476
  reset_on_gap_s: 1.0
  min_dt_s: 1.0e-06
- name: butter_lowpass_10hz
  type: butterworth_lowpass_2nd
  cutoff_hz: 10.0
  family: primary_lowpass_sweep
  deployment_priority: balanced_default_region
  sample_rate_hz: 100.0
  q: 0.7071067811865476
  reset_on_gap_s: 1.0
  min_dt_s: 1.0e-06
- name: butter_lowpass_12hz
  type: butterworth_lowpass_2nd
  cutoff_hz: 12.0
  family: primary_lowpass_sweep
  deployment_priority: fidelity_biased
  sample_rate_hz: 100.0
  q: 0.7071067811865476
  reset_on_gap_s: 1.0
  min_dt_s: 1.0e-06
- name: butter_lowpass_15hz
  type: butterworth_lowpass_2nd
  cutoff_hz: 15.0
  family: fidelity_biased_lowpass_sweep
  deployment_priority: fidelity_biased
  sample_rate_hz: 100.0
  q: 0.7071067811865476
  reset_on_gap_s: 1.0
  min_dt_s: 1.0e-06
- name: butter_lowpass_18hz
  type: butterworth_lowpass_2nd
  cutoff_hz: 18.0
  family: fidelity_biased_lowpass_sweep
  deployment_priority: fidelity_biased
  sample_rate_hz: 100.0
  q: 0.7071067811865476
  reset_on_gap_s: 1.0
  min_dt_s: 1.0e-06
- name: butter_lowpass_20hz
  type: butterworth_lowpass_2nd
  cutoff_hz: 20.0
  family: fidelity_biased_lowpass_sweep
  deployment_priority: fidelity_biased
  sample_rate_hz: 100.0
  q: 0.7071067811865476
  reset_on_gap_s: 1.0
  min_dt_s: 1.0e-06
- name: butter_lowpass_25hz
  type: butterworth_lowpass_2nd
  cutoff_hz: 25.0
  family: fidelity_biased_lowpass_sweep
  deployment_priority: weak_smoothing_control
  sample_rate_hz: 100.0
  q: 0.7071067811865476
  reset_on_gap_s: 1.0
  min_dt_s: 1.0e-06
- name: one_pole_lowpass_4hz
  type: lowpass_1pole
  cutoff_hz: 4.0
  family: causal_live_lowpass
  reset_on_gap_s: 1.0
  min_dt_s: 1.0e-06
- name: one_pole_lowpass_6hz
  type: lowpass_1pole
  cutoff_hz: 6.0
  family: causal_live_lowpass
  reset_on_gap_s: 1.0
  min_dt_s: 1.0e-06
- name: one_pole_lowpass_8hz
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

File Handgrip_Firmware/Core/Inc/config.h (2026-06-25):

/**
 ******************************************************************************
 * @file    config.h
 * @author  Nicolas Schiappacasse <nicolaschiappacase@gmail.com>
 * @date    05/2026
 * @brief   Calibration-ready Handgrip firmware configuration.
 *
 * The firmware emits the D2 calibration payload expected by the LSL_Bridge 
 * and by the Handgrip_Calibration module:
 *
 *   M2,&lt;schema&gt;,&lt;fw_version&gt;,&lt;git_sha&gt;,&lt;hx711_rate_hz&gt;,&lt;scale_factor&gt;,&lt;scale_offset&gt;,&lt;unit&gt;
 *   D2,&lt;seq&gt;,&lt;timestamp_us&gt;,&lt;raw_count&gt;,&lt;current_units&gt;,&lt;status&gt;
 *
 * Raw counts are always present so that calibration fits are not contaminated
 * by mutable firmware scale/offset settings. The current_units field is a
 * convenience/sanity channel computed from the same constants that will later be
 * updated from the calibration report.
 ******************************************************************************
 */
#ifndef _INC_CONFIG_H_
#define _INC_CONFIG_H_

/** @addtogroup HandGrip
 * @{
 */
/** @addtogroup Application
 * @{
 */
/** @addtogroup Config
 * @{
 */

#include <stdbool.h>

/*----------------------------------------------------------------------------*/
/** @ingroup PUBLIC_Definitions                                                */
/**@{                                                                         */
/*----------------------------------------------------------------------------*/

/** --------------------- > Serial Communication < -------------------------- */

/** Serial port baud rate. */
#define SERIAL_BAUD_RATE               115200U


/** ----------------------> Sampling < -------------------------------------- */

/**
 * HX711 calibration constants using the common HX711 convention:
 *
 *   current_units = (raw_count - SCALE_OFFSET) / SCALE_FACTOR
 *
 * Handgrip_Calibration exports recommended firmware constants in this form.
 * During initial characterization keep SCALE_FACTOR=1 and SCALE_OFFSET=0 so
 * current_units mirrors raw_count while raw_count remains authoritative.
 */
#define SCALE_FACTOR                   1.0F
#define SCALE_OFFSET                   0.0F

/** Sampling period in microseconds - 5000us = 5ms = 200Hz
 *  Empirical maximum frequency for the HX711 is ~93Hz (see HX711_EXPECTED_OUTPUT_RATE_HZ).
 *  Sampling is done at >= 2 x 93Hz allows for non-blocking reads on IRQ.
 *  If sensor is not ready, 200Hz ensure that the new sample will be captured
 *  within the next IRQ.
 */
#define SAMPLING_PERIOD_US             5000U


/** ----------------------> Payload Schema < -------------------------------- */

/** Payload schema. Only schema 2 is supported by this upgraded release. */
#define HANDGRIP_PAYLOAD_SCHEMA        2U

/** Status bitfield emitted in D2 frames. */
#define HANDGRIP_STATUS_OK             0x0000U
#define HANDGRIP_STATUS_FIFO_OVERFLOW  0x0001U
#define HANDGRIP_STATUS_HX711_NOTREADY 0x0002U
#define HANDGRIP_STATUS_SCALE_INVALID  0x0004U

/** Human-readable physical unit for current_units. 
 *  Recommended calibration unit is Newtons. */
#define HANDGRIP_FORCE_UNIT            "N"

/** --------------------- > Metadata < -------------------------------------- */

/** Firmware semantic version printed in the M2 boot metadata line. */
#define HANDGRIP_FIRMWARE_VERSION      "2.0.0-calibration-schema"

/** Build/source identifier. Override at compile time with -DFIRMWARE_GIT_SHA=\"...\" if desired. */
#ifndef HANDGRIP_FIRMWARE_GIT_SHA
#define HANDGRIP_FIRMWARE_GIT_SHA      "unknown"
#endif

/** Nominal/expected HX711 output rate used only for metadata. */
#define HX711_EXPECTED_OUTPUT_RATE_HZ  93.0F



/** @} */
/*----------------------------------------------------------------------------*/
/** @ingroup PUBLIC_Types                                                      */
/**@{                                                                         */
/*----------------------------------------------------------------------------*/

/** @} */
/*----------------------------------------------------------------------------*/
/** @ingroup PUBLIC_Data                                                       */
/**@{                                                                         */
/*----------------------------------------------------------------------------*/

/** @} */
/*----------------------------------------------------------------------------*/
/** @ingroup PUBLIC_API                                                        */
/**@{                                                                         */
/*----------------------------------------------------------------------------*/
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

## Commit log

2026-03-19 feat: add last version of project deliverables
    [AC3E v0.f3d, Calib.csv, Calibration.ods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]
2026-03-19 refactor: reorganization of the repo - clarificación entre deprecado y actual
    [AC3E v0.f3d, Calib.csv, Calibration.ods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]
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2026-03-27 req: create comprehensive technical documentation for Handgrip/README.md covering Device_Application and Device_Calibration projects
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2026-03-27 Add handgrip LSL bridge implementation and initial data file
    - Introduced `handgrip_lsl_bridge.py` for handling serial data from handgrip device and streaming it via LSL.
    - Implemented CSV sink for logging parsed samples.
    - Added line parsing logic for different formats (tagged CSV, simple CSV, legacy pair lines).
    - Created utility functions for serial port management and LSL outlet configuration.
    - Added a new binary data file `sub-P001_ses-S001_task-Default_run-001_eeg.xdf`.
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2026-04-03 fix: add missing fields to slotted dataclasses
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2026-04-03 fix: update serial port configuration from /dev/ttyACM0 to /dev/ttyUSB0
    [config.yaml]
2026-04-03 feat: enhance README with detailed modes and data-flow architecture for Handgrip Real-Time Viewer
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2026-04-03 feat: add LabRecorder configuration file and update .gitignore for data directory
    [LabRecorder.cfg]
2026-04-03 feat: add signal characterization lib
    [capture_manifest_template.csv, sample_rest_capture.csv]
2026-04-03 feat: record stage1
    [capture_manifest_template.csv]
2026-04-03 feat: record stage2
    [capture_manifest_template.csv]
2026-04-03 feat: record stage3
    [capture_manifest_template.csv]
2026-04-03 feat: record stage4
    [20260402_stage4_fast_max_trial01.csv, 20260402_stage4_ramp_hold_trial01.csv, 20260402_stage4_sustained_hold_trial01.csv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]
2026-04-03 feat: add analysis results for stages 1 to 4 including summaries and visualizations
    [event_metrics.csv, filtered_psd_peaks.csv, raw_psd_peaks.csv]
2026-04-03 fix: update sampling period to 200Hz and add sensor readiness check, to avoid missing SPI CLK cycles and thus getting incorrect values
    [config.h, main.cpp]
2026-04-03 feat: record stage1 after fix
    [config.yaml]
2026-04-03 feat: record stage2 after fix
    [config.yaml]
2026-04-03 feat: record stage3 after fix
    [config.yaml]
2026-04-03 feat: record stage4 after fix
    [20260402_stage4_fast_max_trial01.csv, 20260402_stage4_ramp_hold_trial01.csv, 20260402_stage4_sustained_hold_trial01.csv]
2026-04-03 feat: add analysis results for stages 1 to 4 after fix, including summaries and visualizations
    [event_metrics.csv, filtered_psd_peaks.csv, raw_psd_peaks.csv]
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2026-04-03 feat: add stage 6 analysis results including new CSV files, images, and summary data
    [filter_comparison.csv, filter_family_assessment.csv, rest_psd_peaks.csv]
2026-04-08 feat: implement -as default- filter based on statistic analysis result from Handgrip_Analysis
2026-04-08 feat: add new images and comprehensive PM58 acquisition board manual for improved documentation
2026-04-16 Add acquisition board GUI and configuration file
    - Implemented a new GUI for high-speed acquisition instrument using NiceGUI.
    - Added functionality for serial communication with Modbus RTU and Active Send protocols.
    - Created a configuration file (config.yaml) to manage application settings, including UI parameters, serial settings, and device configurations.
    - Introduced data logging and visualization features for real-time monitoring of measurements.
2026-04-21 Update PM58 Acquisition Board Manual: Correct image references and enhance clarity
    - Changed the reference for the original certificate photo to a more descriptive filename.
    - Added missing image references for clarity in various sections.
    - Ensured all figures are consistently referenced throughout the document.
    - Improved the layout and organization of image references to enhance user understanding.
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2026-04-21 fix: update default baud rate and active send frequency code in config.yaml
    [config.yaml]
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2026-04-21 feat: add comprehensive Modbus RTU vs. Modbus Active report detailing architecture and data flow
2026-04-21 feat: add dual-device calibration configuration report for HX711 and RS485 load-cell acquisition board feat: add calibration configuration report for load cell devices detailing synchronization and p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
2026-04-22 feat: update RS485 mode and transport settings to 500 Hz for improved calibration accuracy
2026-04-22 feat: update serial baudrate to 460800 and change device mode to active_send for enhanced performance
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2026-04-22 feat: update initialization workflow for acquisition board with detailed connection instructions and parameter reference
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2026-04-28 feat: enhance IPC publisher management by deferring binding until connection starts
    [config.yaml]
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2026-05-01 feat: refactor from single stream 5ch to 2 stream 2ch 93~100Hz & 3ch 500Hz to avoid introducing freq artifacts.
    [config.yaml]
2026-05-01 feat: update timestamp policy for Active-Send batches to prevent ref_shift drift and adjust clock reanchor threshold
    [config.yaml]
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2026-05-05 fix: update channel map for target and reference streams in protocol_static_staircase.yaml
    [protocol_static_staircase.yaml]
2026-05-06 Enhance report generation with candidate model predictions and metrics
    - Introduced candidate prediction functionality to generate model outputs without refitting.
    - Added selection logic for candidate models based on fit results.
    - Improved plot generation to include comparisons of all deployable candidate models.
    - Enhanced residual analysis for selected models and added metrics visualization.
    - Updated report generation to include candidate model metrics and selection likelihoods.
    - Improved error handling for JSON loading and candidate model extraction.
    [default.yaml, protocol_static_staircase.yaml, template.yaml]
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2026-05-12 feat: enhance target timestamping with drift guard and monotonic timestamping
    [config.yaml]
2026-05-13 refactor: refactor Handgrip_Analysis to python standard using src-layout
    [capture_manifest_template.csv, event_metrics.csv, filter_comparison.csv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]
2026-05-13 feat: add calibration data records for handgrip noise characterization
    [20260402_stage4_fast_max_trial02.csv, 20260402_stage4_ramp_hold_trial02.csv, 20260402_stage4_sustained_hold_trial02.csv]
2026-05-13 fix: rename with correct date
    [20260512_stage4_fast_max_trial02.csv, 20260512_stage4_ramp_hold_trial02.csv, 20260512_stage4_sustained_hold_trial02.csv]
2026-05-13 feat: update headers of old data to new standard
    [20260402_stage4_fast_max_trial01.csv, 20260402_stage4_ramp_hold_trial01.csv, 20260402_stage4_sustained_hold_trial01.csv]
2026-05-13 feat: Implement Phase 1 analysis pipeline for handgrip trials
    - Add pipeline.py to orchestrate trial analysis, including building analysis plans, executing trials, and writing outputs.
    - Enhance report.py to support JSON serialization of complex data types, including handling NaN and infinite values.
    - Create stages module with individual stage analyzers for each phase of the handgrip analysis, including warmup, noise characterization, drift analysis, dynamics, interference comparison, and filter review.
    - Introduce common utilities for stage analyzers in common.py to streamline metric calculations and data handling.
    - Implement uncertainty helpers in uncertainty.py for robust statistical su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
    [calibration_manifest.csv]
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2026-05-13 feat: Add new manifest files for handgrip trials and stages
    [all_runnable_manifest.csv, analysis_stages_1_4_manifest.csv, calibration_manifest.csv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]
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2026-05-13 feat: add new handgrip characterization trial
    [20260512_stage4_fast_max_trial03.csv, 20260512_stage4_ramp_hold_trial03.csv, 20260512_stage4_sustained_hold_trial03.csv]
2026-05-13 feat: add trial 03 data to all stage manifests for consistency in handgrip analysis
    [all_runnable_manifest.csv, analysis_stages_1_4_manifest.csv, stage1_manifest.csv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]
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2026-05-14 feat: port of viewer to nice-gui. Too slow to handle data
    [config.yaml]
2026-05-14 feat: update LSL Viewer to v0.4.1 with improvements and fixes
    - Enhanced rendering performance by switching to Apache ECharts with NiceGUI.
    - Introduced render budgeting to limit browser payload size for time series and XY data.
    - Updated documentation to reflect changes in functionality and configuration.
    - Refactored chart handling to ensure explicit ownership of options in ECharts.
    - Added tests for render budgeting and EChart sink binding to ensure correctness.
    - Fixed issues with XY data representation, ensuring all entries are display-ready points.
    [config.yaml]
2026-05-15 Remove deprecated HX711 calibration scripts and associated sample files
    - Deleted SPI_read.py, Sig_Record.py, damped.py, filter_coefs.py, neville.py, peak_detect.py, psd.py, twocomp.py, vel_acc_test.py, and firmware files (HX711_write_calibration_data.ino, HX711_main.ino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
    - Removed sample files (01_t.npy, 02_t.npy, 03_t.npy, baseline_00.npy) from the DSP-Experiments directory.
    - Cleaned up the Tests directory by removing Interrupts.ino, Reading.ino, and SlaveSPI example files (Master.c, Slave.c).
    [behaviour.ods, calib_session1.csv]
2026-05-15 Remove obsolete calibration scripts and documentation
    - Deleted `apply_linear-regression.py` and `read_calibration_data.py` scripts as they are no longer needed for the calibration process.
    - Removed the `README.md` file which contained outdated information regarding the calibration workflow and device architecture.
    [Calib.csv, Calibration.ods, Calibration.xlsx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]
2026-05-15 Remove obsolete 3D model files: Ring.stl, Screw.stl, Soporte.stl, and their versions from the repository.
    [AC3E v0.f3d, Ring.stl, Screw.stl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]
2026-05-15 Remove obsolete LabRecorder configuration file
    [LabRecorder.cfg]
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2026-05-15 feat: update Doxygen comments and fix XML escaping in documentation
    [config.h, main.cpp]
2026-05-16 Phase3: Add hardware documentation and image assets for PM58 and acquisition board
    - Created README.md for hardware image asset map detailing image usage and naming conventions.
    - Added various image assets related to the PM58 load cell and acquisition board, including terminal maps and setup images.
    - Introduced force-fixture.md to document the mechanical setup for calibrating the Handgrip target with the PM58 load cell.
    - Added pm58-wiring-and-bringup.md to provide a comprehensive wiring and bring-up manual for the PM58 load cell and acquisition board.
    - Included several PDF references related to the acquisition board and HX711 for additional documentation.
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2026-05-16 Phase 6.2: Add comprehensive documentation for Handgrip Firmware
    - Introduced `build-and-upload.md` to guide users through the firmware build and upload process using PlatformIO.
    - Created `configuration.md` detailing configuration sources, constants, and safe editing practices for firmware settings.
    - Updated `index.md` to reflect new documentation structure and clarify firmware purpose and audience.
    - Enhanced `serial-protocol.md` with detailed descriptions of the current D2/M2 protocol, including frame structures and validation points.
    - Established `troubleshooting.md` to assist users in diagnosing common issues related to firmware build, upload, and serial output.
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2026-05-16 Phase6.4: Add comprehensive documentation for LSL Bridge development, quickstart, and timestamping
    - Introduced a new development guide detailing safe practices for adding channels, changing parser behavior, and adding processing stages.
    - Created a quickstart guide to assist users in starting the LSL Bridge and confirming expected LSL streams.
    - Added a detailed timestamping document outlining timestamp policies, drift behavior, and validation commands.
    - Updated the main index and stream contracts documentation to reflect new content and improve clarity.
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2026-05-16 Phase9 & 10: Add comprehensive troubleshooting documentation for calibration and analysis
    - Introduced new troubleshooting guides for various components:
    - Analysis Pipeline Troubleshooting
    - Calibration Recording Troubleshooting
    - Hardware and Wiring Troubleshooting
    - LSL Streams Troubleshooting
    - Serial and RS485 Troubleshooting
    - Viewer Lag or XY Delay Troubleshooting
    Each guide follows a symptom-first approach, detailing likely causes, checks, fixes, and validation commands to assist users in diagnosing and resolving issues effectively.
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2026-05-19 Refactor documentation and workflows for Handgrip Suite
    - Added new image asset for sensor to ADC module.
    - Updated hardware documentation index for clarity and conciseness.
    - Revised PM58 wiring and bring-up manual for improved audience guidance.
    - Overhauled main documentation index for better navigation and organization.
    - Enhanced system overview to clarify measurement chains and workflows.
    - Streamlined troubleshooting documentation for analysis pipeline and calibration recording.
    - Simplified handgrip analysis and calibration workflows, focusing on essential steps and commands.
    - Corrected references to configuration and workflow documentation across various files.
    - Improved physical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
2026-06-03 Add calibration manual and update documentation links
    - Introduced a comprehensive calibration manual in `docs/calibration-manual.md` detailing the handgrip calibration workflow, including setup, procedures, and validation criteria.
    - Updated links in `docs/development.md` to point to the correct paths for protocol and fitting documentation.
    - Enhanced `docs/index.md` to include the new calibration manual and ensure all document links are prefixed with the project path for clarity.
    - Revised `docs/recording.md` to provide a more detailed reference for acquisition board configuration, linking to the dual-device calibration configuration document for better guidance.
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2026-06-03 docs: update calibration documentation by removing outdated manual, adding drift tracking section, enhancing recording preflight gates, and including dynamic validation targets
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2026-06-04 Refactor filter application to support production real-time filters
    - Updated `apply_filter_spec` to handle production real-time filter types, ensuring compatibility with LSL_Bridge.
    - Introduced new filter classes for identity and first/second-order low-pass filters.
    - Replaced legacy filter types with their production equivalents in the codebase.
    - Enhanced filter specification loading to validate against production types only.
    - Updated tests to reflect changes in filter specifications and ensure proper functionality.
    - Removed unsupported filter types from the pipeline, enforcing a stricter contract for active filters.
    [candidates.yaml]
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2026-06-04 Add detailed production-filter workflow documentation and remove old workflow file
    - Introduced a comprehensive workflow document for the Handgrip Analysis production-filter process, covering steps from calibration completion to filter deployment and validation.
    - Removed the outdated workflow document to streamline documentation and avoid confusion.
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2026-06-04 feat: Add visual references and documentation updates for hardware setup
    - Introduced new images for the acquisition board and force fixture documentation.
    - Enhanced the dual-device calibration configuration with visual references.
    - Updated the force fixture documentation to include detailed image references and context.
    - Created a structured reference system for hardware PDFs, including original manuals and datasheets.
    - Improved the PM58 wiring and bring-up guide with visual aids for better clarity.
2026-06-04 feat: Refactor channel mapping in configuration files and enhance signal resolution in segmentation
    - Updated channel mapping in YAML configuration files to use lists for better clarity and structure.
    - Introduced new functions to resolve signal columns in segmentation, ensuring that numeric fallbacks do not default to channel_0, which is often a sequence counter.
    - Added tests to verify that legacy CSVs correctly utilize configured numeric fallbacks without using channel_0 as a raw signal.
    - Implemented a new script for analyzing step-hold relaxation metrics, generating various diagnostic outputs including CSVs and plots.
    [config.yaml, default.yaml, protocol_creep_zero_return.yaml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]
2026-06-04 feat: Add relaxation metrics and artifact correction for calibration holds
    - Introduced `relaxation.py` module to compute hold relaxation metrics, including start/end medians, slopes, and exponential diagnostics.
    - Implemented functions for tail frame extraction, shape correlation, and direction sign matching.
    - Enhanced `segmentation.py` to integrate relaxation metrics and artifact correction into the hold segmentation process.
    - Updated `segment_accepted_holds` to handle calibration artifact compensation, producing direction-balanced fit points.
    - Added tests for legacy channel resolution and direction-balanced artifact dataset generation.
    [config.yaml, default.yaml, protocol_creep_zero_return.yaml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]
2026-06-04 docs: Update Handgrip_Calibration documentation against recent implementation changes
    Align documentation with commits abe2c6b and 6c7126e:
    - workflow.md: Update Step 1 channel_map YAML from scalar format to [name, index]
    lists. Add conditional artifact files to Step 4 and final artifacts listing.
    - architecture.md: Add relaxation.py to module responsibilities table.
    - reports-and-outputs.md: Add calibration_hold_dataset_raw.csv and
    calibration_artifact_summary.csv to expected output classes table. Add new
    section documenting calibration_dataset.csv columns introduced by relaxation
    metrics and artifact correction.
    - configuration.md: Add explanatory subsection on channel_map [nam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
2026-06-12 feat: Add diagnostics configuration and recording for XY staircase investigation
    - Introduced DiagnosticsCfg class for enabling diagnostics in the viewer configuration.
    - Implemented DiagnosticsRecorder to handle recording of metrics and raw samples.
    - Added compute_tick_metrics and helper functions for calculating metrics related to target and reference samples.
    - Integrated diagnostics recording into the live mode tick function.
    - Updated ViewerState to include metrics for XY pairing diagnostics.
    - Enhanced update_charts to populate diagnostics state.
    - Created unit tests for diagnostics functionality, ensuring metrics are recorded correctly and files are created as expected.
    - Added new c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
    [config.yaml]
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2026-06-18 feat: Implement asynchronous publishing for IPC records to enhance performance and prevent blocking during data acquisition
    [config.yaml]
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2026-06-25 fix: Update sampling frequency comment in config.h and enhance CSV field order in stream-contracts.md; clarify live system execution steps in README.md
    [config.h]
2026-06-26 Remove outdated calibration report reference source inventory and concept inventory documents
    - Deleted `calibration-report-reference-source-inventory.md` as it is no longer needed.
    - Deleted `report-concept-inventory.md` to streamline documentation and remove redundancy.
